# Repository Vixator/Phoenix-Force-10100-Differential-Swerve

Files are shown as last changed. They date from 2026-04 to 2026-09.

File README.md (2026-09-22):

# Differential Swerve Drivetrain

This project implements a two-pod **differential swerve** drivetrain for an FTC robot. Each pod uses two motors whose combined motion controls wheel speed and pod azimuth. Driving and steering share the available motor-speed capacity.

The main TeleOp is **robot-centric** and uses four drive motors and two dedicated pod encoders. Pedro commissioning and autonomous OpModes additionally use a guarded Pinpoint localizer; TeleOp does not require Pinpoint. See [hardware.md](hardware.md) for wiring, specifications, calibration, and tuning notes, [PROJECT_DESIGN.md](PROJECT_DESIGN.md) for architecture and design decisions, and [HUMAN_TASKS.md](HUMAN_TASKS.md) for every physical calibration and commissioning task.

## Pedro integration and verification

The robot pins `com.pedropathing:revhub:3.0.1` and FTC SDK 12.0.0. Pedro commands use forward +X, left +Y, and CCW-positive yaw; positions are inches and headings are radians. `DifferentialSwerveRuntime` owns the shared lifecycle, `DifferentialPod` preserves the calibrated control/motor mapping, and `SafePedroFollower` stops immediately on faults or Stop. Every follower update validates fresh hub feedback, reads Pinpoint once, and checks authorization before each motor write. Autonomous hub recovery cancels the run; TeleOp retains its neutral-stick recovery interlock.

Run `./gradlew.bat :TeamCode:testDebugUnitTest :TeamCode:assembleDebug`. For tests against the neighboring library's actual artifacts and then published Pedro, use `../PedroSwerving/scripts/verify-projects.ps1`. See [INTEGRATION_STATUS.md](INTEGRATION_STATUS.md) for commands, source responsibilities, tested behavior, and limitations.

Pinpoint direction/heading verification and the measured Foresight model remain closed gates. `PedroLineTest`, `PedroCurveTest`, `PedroHeadingTest`, and `PedroAutoTemplate` retain `@Disabled`. Follow [HUMAN_TASKS.md](HUMAN_TASKS.md) in order; successful builds do not authorize changing measured-value flags.

The compiled [PedroAutoTemplate](TeamCode/src/main/java/org/firstinspires/ftc/teamcode/PedroAutoTemplate.java) shows the complete lifecycle:

```java
PedroAutoDrive drive = new PedroAutoDrive(this);
try {
    if (!drive.initialize()) return;
    Follower follower = drive.follower();
    Pose start = new Pose(0, 0, 0);
    Path path = Paths.line(start, new Pose(12, 0, 0)).constant(start.heading());
    follower.holdEnd.set(false);
    waitForStart();
    if (isStopRequested()) return;
    drive.enableForesight(); // Validate measured model while disarmed.
    drive.arm(start);
    follower.follow(path);
    long deadline = System.nanoTime() + 10_000_000_000L;
    while (opModeIsActive() && follower.following() && !drive.hasFault()) {
        if (System.nanoTime() >= deadline) { drive.abort("Path deadline"); break; }
        follower.update();
        idle();
    }
    follower.stop();
    // Also assess terminal pose/velocity: parametric completion alone is not accuracy.
} finally {
    drive.close();
}
```

The path diagnostics additionally detect lack of progress and report `END_WITHIN_TOLERANCE`, `END_OUTSIDE_TOLERANCE`, `INVALID_TERMINAL_FEEDBACK`, `OPERATOR_STOP`, or `FAULT`. Endpoint acceptance checks 0.5 in, 3 degrees, 1 in/s, and 5 degrees/s independently of Foresight's completion flag. Out-of-tolerance/invalid completion latches a fault.

`Pedro Drive Characterization` logs signed timestamped CSV samples under the `PedroCharacterization` Robot Controller log tag at up to 50 Hz, including body velocity, pose, commands, drive scale, and battery voltage. Its telemetry runs at 10 Hz. See the collection and fitting procedure in [HUMAN_TASKS.md](HUMAN_TASKS.md).

## Hardware Configuration

The [drive TeleOp](TeamCode/src/main/java/org/firstinspires/ftc/teamcode/DifferentialSwerveTeleOp.java) expects four goBILDA 5203-2402-0005, 1150 RPM motors on the Control Hub:

| Port | Name | Description |
| :--- | :--- | :--- |
| `0` | `motor0` | Left Pod: LEFT Motor |
| `1` | `motor1` | Left Pod: RIGHT Motor |
| `2` | `motor2` | Right Pod: LEFT Motor |
| `3` | `motor3` | Right Pod: RIGHT Motor |

All four drive motors use software direction `FORWARD`. Individual testing confirmed joystick-up/positive command rotates `motor0` and `motor2` counterclockwise, while `motor1` and `motor3` rotate clockwise, viewed from above; joystick-down reverses each response. Physical testing found that the right pod requires its logical motor pair to be negated and swapped at the hardware boundary. This reverses equal-command wheel drive while leaving opposite-command pod steering unchanged. Drive-motor encoders provide motor velocity/count feedback, but the active drive controller uses the dedicated pod quadrature encoders for pod-position feedback.

Two **Melonbotics Through Bore Encoders** provide absolute analog startup position and quadrature tracking. Their quadrature connections on the Expansion Hub are unchanged:

| Encoder Port | Configuration Name | Measurement |
| :--- | :--- | :--- |
| `0` | `encoderleft` | Left pod azimuth |
| `1` | `encoderright` | Right pod azimuth |

Configure these names on the corresponding Expansion Hub **motor channels** so the SDK can access the encoder inputs. No motors need to be attached; quadrature channels are read-only and never receive output or hardware-reset commands. The diagnostic’s explicit alignment action commands only the selected drive pod motors. Each encoder body contains both outputs and is mechanically **1:1 with pod rotation**. Melonbotics specifies **1024 CPR quadrature output resolution** on the 4-pin JST. The code uses **4096 raw counts per pod revolution**: a power-of-two scale consistent with the 1024 CPR encoder using 4x quadrature decoding and the approximately 4100-count measurement from both pods.

| Control Hub Analog Channel | Configuration Name | Measurement |
| :--- | :--- | :--- |
| `0` | `absencleft` | Left pod absolute azimuth |
| `1` | `absencright` | Right pod absolute azimuth |

Both analog signals use **ONE joiner cable into the physical analog connector labeled 0-1**. They remain independent inputs and require **two hardware names**, not one shared name. Move one pod at a time to verify channel assignment. The encoder output is **0..3.2 V** at 3.3 V supply; raw angle is `volts / 3.2 * 360`, not scaled by the hub's maximum input voltage. See [hardware.md](hardware.md) for manufacturer sources.

## Controls

Select **Differential Swerve TeleOp** on the Driver Station.

- **Left stick:** Robot-relative direction and speed. Up means robot-forward, right means robot-right. Translation uses a radial deadband followed by linear magnitude scaling.
- **Right stick X:** Rotation about the midpoint between the pods. Right commands clockwise/right rotation viewed from above. Rotation uses a deadband and cubic shaping. The measured pod-steering motor polarity is applied separately inside each pod controller.
- **Full-stick rotation:** With translation centered and pods aligned, both pods receive the physical motor signs needed to roll their wheels in opposite chassis directions (about ±2781 ticks/s). Left turn reverses these signs. Steering corrections retain priority, and combined translation/rotation is normalized to fit the motor limits.
- **Release right stick:** Commands zero chassis rotation; it does not actively hold a heading.
- **Triggers:** Not used for driving.

### Startup

1. Complete the physical calibration and verification checklist in [HUMAN_TASKS.md](HUMAN_TASKS.md) first. The measured top-dead-center references are now recorded as `LEFT_FORWARD_DEGREES = 13.725` (0.122 V) and `RIGHT_FORWARD_DEGREES = 29.025` (0.258 V). `CALIBRATION_VERIFIED` is now `true`; hardware configuration, encoder signs/scale, individual motor behavior, and combined pod steering direction have been verified. Previously reported low-speed driving passed; repeat those checks after the shared-runtime refactor, then finish fault testing and loaded tuning.
2. Press **INIT** with the wheels securely raised for commissioning. **The pods move during INIT:** the drive immediately steers both to their independent analog forward references.
3. Alignment is capped at 0.20 command and must remain inside a 2° target window for 100 ms before completion, within a 5-second timeout. Either pod failing stops both. Wait for **READY — pods aligned. Press Start to drive.** Motors receive zero velocity while waiting. An early Start cannot bypass unfinished alignment.
4. Press **Start** to drive. A fresh snapshot verifies the pods are still aligned and seeds quadrature with the measured residual angle. Moving a pod away from forward while waiting requires reinitialization. Runtime then uses quadrature only. At zero requested pod velocity the previous azimuth target is retained. A completely zero chassis request sends true zero to every motor with BRAKE; it does not actively steer.

Analog readings accept 0..3.3 V; the 3.2..3.3 V upper margin is clamped to the wrap endpoint while angle conversion retains the documented 3.2 V scale. Alignment telemetry shows both raw voltages, and analog faults report the measured voltage. The previous exact-3.2 V cutoff could reject a slightly overscale reading; the earlier generic fault did not establish the actual voltage.

An invalid hub read immediately commands zero velocity, then retries the complete snapshot up to three total attempts within 150 ms, with 10 ms between attempts. A recovered read during driving requires both sticks centered before motion resumes and checks analog/quadrature agreement without reseeding. Persistent failure or a loop delay above 250 ms latches a **DRIVE STOPPED** telemetry state until Stop/reinitialization instead of throwing an uncaught feedback exception. Telemetry/logs identify the configured hub, connection, and recovered-read count. Real motor response and communication recovery still require robot testing.

### Investigating an intermittent stopped pod

The drive now publishes numeric Dashboard series for each motor's target velocity, measured velocity, and encoder count, plus each pod's requested speed, drive/steer commands, angle error, quadrature angle/count/rate, absolute voltage/angle, and wrapped `quadrature minus absolute (deg)`. Motor and analog readings reuse the bulk snapshots. Absolute angles are diagnostic during normal driving; they do not correct or reseed quadrature.

If the right pod stops, capture these values **before using counterclockwise rotation to recover it**, including a brief translation-only request with the rotation stick centered:

- Graph `motor2 target (ticks/s)` and `motor3 target (ticks/s)` against their `measured (ticks/s)` series. Nonzero targets with near-zero measured speeds point toward motor response, velocity-loop, encoder, or mechanical trouble; they do not by themselves identify which one. Counts help distinguish actual movement from a bad velocity reading.
- Compare `Right requested speed (normalized)`, `Right drive command`, `Right steer command`, and `Right angle error (deg)`. Drive is deliberately suppressed near a 90-degree steering error, but steering should continue. A zero wheel-speed average alone does not mean both motors are stopped.
- Compare `Right quadrature angle (deg)` against `Right absolute angle (deg)`. A persistent discrepancy while stationary suggests a feedback/calibration problem. Brief differences during motion may reflect the two hubs' sampling times.
- Forward plus clockwise turn can cancel the right pod's requested vector, holding its previous angle. Centering rotation must restore a translation request. Remaining stuck after that is not explained by this normal cancellation.

The reported symptom is an intermittent right-module stop relieved by rotation-stick input; the exact triggering inputs and whether translation alone clears it are unconfirmed. Two code paths can resemble this:

- **Partial-stick cancellation:** roughly 16.875% forward stick and 52.5% clockwise turn stick produce equal forward and rotation contributions at the right pod. Its requested speed becomes zero while the left still drives. Increasing or decreasing rotation removes the cancellation. Near-cancellation produces very low speed, and even a small sideways input can change the requested pod angle sharply.
- **Alignment suppression plus unsuccessful steering:** cosine-squared scaling leaves about 3% of wheel drive at 80° error and zero at 90°. The controller still requests steering, capped at 20% of maximum motor velocity (about 556 ticks/s per motor in pure steering, not a 20% electrical-power limit). If the physical pod cannot execute that correction, wheel drive stays suppressed. Rotation input changes the target angle and can restore drive without the pod first moving. This explains a possible mechanism, not a confirmed hardware fault.

Controller tests cover those two command patterns and mixed-input histories followed by translation using a simple motor/encoder model on both pods. They do not reproduce real friction, binding, hub velocity-loop behavior, or intermittent wiring faults. SDK 12.0 source review confirms that explicit `getBulkData()` refreshes the manual cache and `setMotorVelocity()` sends a velocity command on every call. Neither is a change-only cache requiring joystick movement to refresh it. The stall has not been attributed to a confirmed code defect; record a Dashboard graph or Driver Station video of the event to identify the next targeted fix.

### Encoder Test

Select [Swerve Pod Encoder Test](TeamCode/src/main/java/org/firstinspires/ftc/teamcode/SwervePodEncoderTest.java). Its normal measurement path is read-only, and its explicit Y alignment action commands only the selected pod’s drive motors. It works during INIT or after Start.

1. Run [Pod Analog Encoder Test](TeamCode/src/main/java/org/firstinspires/ftc/teamcode/PodAnalogEncoderTest.java). LB selects the left pod, RB selects the right pod, A steers the selected pod toward its configured forward analog reference, and B aborts. If a reference has not yet been entered, the test targets analog 0 degrees. Confirm `absencleft` is left/channel 0 and `absencright` is right/channel 1.
2. Run [Individual Motor Drive Test](TeamCode/src/main/java/org/firstinspires/ftc/teamcode/MotorEncoderDriveTest.java) with the robot raised. D-pad selects `motor0`–`motor3` for individual checks. Hold LB to drive the left pod or RB to drive the right pod using the real differential mix; left stick is drive, right stick X is steering, and combined output is capped at 420 ticks/s. The current differential topology is known: each motor drives its own 16:54 path, the 54-tooth gear is fixed to a 50-tooth gear, and the two 50-tooth gears engage the common 19-tooth wheel gear.
3. Run [Swerve Pod Encoder Test](TeamCode/src/main/java/org/firstinspires/ftc/teamcode/SwervePodEncoderTest.java). LB/RB select the pod, A zeroes the selected quadrature display in software, X starts/finishes a manual 360-degree measurement, Y steers the selected pod to its analog forward reference, and B aborts alignment.
4. Check the corresponding quadrature channel and verify a complete revolution is approximately 4096 raw counts with the correct clockwise sign.
5. Confirm wheel rolling without pod rotation does not change the pod encoder reading. The analog zero references are recorded as left 0.122 V / 13.725° and right 0.258 V / 29.025°. Both analog voltages decrease during clockwise rotation, so both analog signs are `-1`. Powered testing confirmed that forward wheel drive, low-speed translation, strafing, rotation, combined motion, and stopping work on the robot. Loaded speed, thermal/current validation, fault handling, and final PID tuning remain; hardware PID tuning is planned through the installed FTC Dashboard dependencies.

The combined test shows raw counts, quadrature degrees, analog voltage/raw degrees, target/error, wrap margins, and full-revolution results during INIT and run. Dedicated [Pod Analog Encoder Test](TeamCode/src/main/java/org/firstinspires/ftc/teamcode/PodAnalogEncoderTest.java) and [Individual Motor Drive Test](TeamCode/src/main/java/org/firstinspires/ftc/teamcode/MotorEncoderDriveTest.java) OpModes are also available. Quadrature zeroes and measurements are intentionally **session-only**, with no hardware reset, persistence, or automatic transfer to the drive; record the results in `HUMAN_TASKS.md` and then update the shared constants.

## Implementation Details

### Kinematics
The code calculates each pod's requested travel vector, then combines wheel drive and steering into motor velocity commands:
- `left motor velocity = drive velocity + steer velocity`
- `right motor velocity = drive velocity - steer velocity`

**Steering polarity fix:** Positive differential steering (`left+ / right−`) physically rotates both pods counterclockwise, while calibrated pod angles increase clockwise. The runtime controller now applies `steer = -(Kp * angleError - Kd * measuredRate)`, matching the working startup alignment. Previously the runtime sign was reversed, causing corrections and damping to reinforce unwanted motion. This explains why alignment could work but joystick motion triggered runaway steering. Chassis right-stick input is clockwise-positive; it is not inverted to compensate for individual pod steering.

Runtime steering defaults are `Kp=0.5`, `Kd=0.01`, a `0.20` steering cap, and a `2.0/s` slew limit. Driver Station telemetry shows each pod's measured angle, optimized target, error, motor velocity targets, and signed left/right module wheel speeds in m/s. Positive module speed is robot-forward and negative is robot-reverse. Module speed is calculated from the average measured velocity of the pod's two motors and the configured encoder, gear, and wheel constants; it is wheel-speed feedback, not independently measured ground speed. These are preliminary settings for robot verification.

Motor commands and velocity telemetry use **encoder ticks/second**, not RPM. The supplied motor specification is 1150 RPM no-load, 5.2:1 planetary gearing, 28 pulses per encoder-shaft revolution, and 145.1 pulses per gearbox-output revolution. The calculated motor limit is approximately 2781.08 ticks/second. Steering receives priority when the combined requests exceed motor capacity; wheel drive uses the remaining headroom.

### Mechanical Ratio and Steering Calibration

The programmed differential gear setup uses a 1:1 initial bevel pair for each motor, then a 16-tooth gear driving a 54-tooth gear. Each 54-tooth gear is rigidly attached to a 50-tooth gear, and the two 50-tooth gears engage the common 19-tooth wheel gear. The programmed wheel-drive ratio is `(16/54) * (50/19) = 0.779727`. Equal motor components drive the wheel; the difference between the motor components steers the pod. This is the ratio and topology reflected in the BOM and source code; the old 24/108 gear description is obsolete.

The 63.25 mm wheel and 1150 RPM motor rating produce a theoretical no-load wheel speed of approximately 2.970 m/s. This is not a loaded operating limit.

### Steering Calibration
The shared [SwervePodEncoder](TeamCode/src/main/java/org/firstinspires/ftc/teamcode/SwervePodEncoder.java) seeds azimuth at Start with `wrap((rawAnalogDegrees - forwardDegrees) * analogSign)`, then uses only the dedicated Expansion Hub quadrature encoders:
`deltaPodAngle = deltaPodEncoderCounts * quadratureSign * (2 * PI / COUNTS_PER_REVOLUTION)`

There is **no runtime analog correction**. Raw controller reads preserve measured polarity independently of motor-channel direction settings. Steering damping uses pod angular rate calculated from successive counts and elapsed time. Both analog signs are `-1`: each encoder's raw voltage decreases during clockwise pod rotation viewed from above. Both quadrature signs are confirmed as `+1` because clockwise motion increases raw counts.

Independent `LEFT_FORWARD_DEGREES` and `RIGHT_FORWARD_DEGREES` absorb the right module's 180-degree mounting rotation. It is rotated, **not mirrored**: do not negate right feedback or add another 180 degrees merely because of its mounting. Both pods remain centered at their existing left/right locations with unchanged kinematics. Encoder calibration does not validate motor directions.

Mechanically indexing each encoder near **1.6 V = 180 raw degrees** at directed forward gives room for +/-100 degrees (about 80 degrees left to the wrap) or +/-80 degrees (about 100 degrees left). A software forward offset does not move the hardware DAC wrap. The analog wrap is neither a dead zone nor a hard steering limit.

### Optimizations
- **Shortest-path steering:** Wheel direction reverses when the equivalent azimuth is closer. A 3° hysteresis band around 90° prevents repeated reversals from small input/encoder noise; the retained choice can require up to 93° of steering. Wheel drive is zero for errors at or above 90°.
- **Alignment scaling:** Wheel drive is reduced by cosine-squared steering error while the pod is misaligned.
- **Steering slew limiting:** Time-based limiting reduces abrupt changes to the steering command.
- **Bulk reads:** One validated snapshot per configured hub per drive loop; encoder getters reuse that snapshot.
- **Telemetry:** Updates at 10 Hz and reuses stored pod counts. Requested-vector angles may differ from optimized pod angles when wheel direction is reversed.
- **Velocity PIDF:** Applied during INIT and reapplied to all four drive motors whenever a Dashboard value changes.

### Tuning and Validation

FTC Dashboard 0.6.0 is installed. The embedded Dashboard server starts with the Robot Controller app; no separate server process is needed for normal use.

1. Build and install the Robot Controller app after dependency changes: `./gradlew.bat :TeamCode:assembleDebug`. Deploy it from Android Studio or with your normal ADB workflow.
2. Connect the computer to the Control Hub Wi-Fi network. Find its password in the Driver Station's **Program and Manage** screen if needed.
3. Open `http://192.168.43.1:8080/dash` for a Control Hub. A phone Robot Controller using Wi-Fi Direct normally uses `http://192.168.49.1:8080/dash` instead.
4. Initialize **Differential Swerve TeleOp**. Open **Config**, expand **SwerveTuning**, edit a value, and press Enter. Runtime steering values take effect on the next control loop. Changed motor PIDF values are detected and written to all four motors while the OpMode runs.
5. Use the Dashboard telemetry graph to select angle/error, motor target velocity, or `Module wheel speed (m/s)` series. Continue to operate the robot from the Driver Station; browser gamepad control is not recommended for drivetrain tuning.

The `SwerveTuning` panel contains all active closed-loop drivetrain settings:

| Dashboard field | Default | Function |
| :--- | ---: | :--- |
| `MOTOR_VELOCITY_P` | `15.0` | REV motor velocity proportional gain |
| `MOTOR_VELOCITY_I` | `0.5` | REV motor velocity integral gain |
| `MOTOR_VELOCITY_D` | `0.5` | REV motor velocity derivative gain |
| `MOTOR_VELOCITY_F` | `11.782...` | REV motor velocity feedforward gain |
| `STEERING_P` | `0.5` | Runtime pod-angle proportional gain, using radians |
| `STEERING_D` | `0.01` | Runtime pod angular-rate damping gain, using rad/s |
| `STEERING_MAX_COMMAND` | `0.20` | Maximum differential steering command |
| `STEERING_SLEW_RATE` | `2.0` | Maximum steering-command change per second |
| `ALIGNMENT_P` | `0.005` | INIT absolute-alignment proportional gain, using degrees |
| `ALIGNMENT_MIN_COMMAND` | `0.03` | Minimum INIT alignment command outside the 2° settling window, to overcome static friction |
| `ALIGNMENT_MAX_COMMAND` | `0.20` | Maximum INIT alignment command |

Dashboard edits change live in-memory values only. Record successful gains and update the defaults in [`SwerveTuning.java`](TeamCode/src/main/java/org/firstinspires/ftc/teamcode/SwerveTuning.java) before rebuilding; do not assume browser edits will survive an app restart or redeployment. Values are validated as finite and nonnegative, command limits must be in `0..1`, the minimum cannot exceed the maximum, and an invalid value stops the OpMode. Tune with the robot raised initially, keep clear during INIT alignment, and change one control layer at a time: motor velocity PIDF first, runtime steering PD second, then INIT alignment P.

The no-load wheel-speed estimate is not a measured loaded limit. Stick deadbands and kinematic limits remain source constants because they are not PIDF controller settings.

The debug APK build and unit tests passed using `./gradlew.bat :TeamCode:testDebugUnitTest :TeamCode:assembleDebug`. Tests cover encoder math, startup/runtime correction agreement, damping direction, strafing, chassis rotation, reverse travel, angle wrap, motor limits, target retention, and closed-loop convergence using a simple motor model. Real-robot testing has additionally confirmed forward wheel drive, low-speed translation, strafing, rotation, combined motion, and stopping. The model verifies feedback direction, not physical tuning. Complete the real-world commissioning checks in [HUMAN_TASKS.md](HUMAN_TASKS.md); tests do not establish physical stability, loaded speed, or hardware loop timing. **Zero volts can be a valid absolute position or a disconnected sensor**; range checks are not reliable disconnect protection. Frozen/disconnected quadrature feedback can also return valid hub data, and runtime analog correction or reliable sensor-disconnect detection is not implemented.

Build from the repository root on Windows with `./gradlew.bat :TeamCode:assembleDebug`.

---

## FOR HACKCLUB STARDANCE
My project is a differential swerve drivetrain for an FTC robot. A differential swerve drive is a holonomic drive, which allows the robot to move in any direction at any time. A differential drive is different from a co-axial swerve drive (used in FRC) as it uses both motors for thrust and direction instead of using one per. This allows for double the power while moving forward and turning, resulting in a faster drivetrain. I made this project mainly for fun and to test my skills in designing and manufacturing. It could benefit my robotics team in the next season, but that varies depending on the actual game presented. 

FINAL ASSEMBLY V1: Too large and not correct speed


V2 In progress, need parts to finish assembly.
\



------------------------------------------------------------------------------------------------------------------------------------------------------------------
## NOTICE

This repository contains the public FTC SDK for the BIOBUZZ (2026-2027) competition season.

## Welcome!
This GitHub repository contains the source code that is used to build an Android app to control a *FIRST* Tech Challenge competition robot.  To use this SDK, download/clone the entire project to your local computer.

## Requirements
To use this Android Studio project, you will need Android Studio Narwhal 3 Feature Drop or later.

To program your robot in Blocks or OnBot Java, you do not need Android Studio.

## Getting Started
If you are new to robotics or new to the *FIRST* Tech Challenge, then you should consider reviewing the [FTC Blocks Tutorial](https://ftc-docs.firstinspires.org/programming_resources/blocks/Blocks-Tutorial.html) to get familiar with how to use the control system:

&nbsp;&nbsp;&nbsp;&nbsp;&nbsp;&nbsp;[FTC Blocks Online Tutorial](https://ftc-docs.firstinspires.org/programming_resources/blocks/Blocks-Tutorial.html)

Even if you are an advanced Java programmer, it is helpful to start with the [FTC Blocks tutorial](https://ftc-docs.firstinspires.org/programming_resources/blocks/Blocks-Tutorial.html), and then migrate to the [OnBot Java Tool](https://ftc-docs.firstinspires.org/programming_resources/onbot_java/OnBot-Java-Tutorial.html) or to [Android Studio](https://ftc-docs.firstinspires.org/programming_resources/android_studio_java/Android-Studio-Tutorial.html) afterwards.

## Downloading the Project
If you are an Android Studio programmer, there are several ways to download this repo.  Note that if you use the Blocks or OnBot Java Tool to program your robot, then you do not need to download this repository.

* If you are a git user, you can clone the most current version of the repository:

<p>&nbsp;&nbsp;&nbsp;&nbsp;&nbsp;&nbsp;&nbsp;&nbsp;&nbsp;&nbsp;&nbsp;&nbsp;git clone https://github.com/FIRST-Tech-Challenge/FtcRobotController.git</p>

* Or, if you prefer, you can use the "Download Zip" button available through the main repository page.  Downloading the project as a .ZIP file will keep the size of the download manageable.

* You can also download the project folder (as a .zip or .tar.gz archive file) from the Downloads subsection of the [Releases](https://github.com/FIRST-Tech-Challenge/FtcRobotController/releases) page for this repository.

* The Releases page also contains prebuilt APKs.

Once you have downloaded and uncompressed (if needed) your folder, you can use Android Studio to import the folder  ("Import project (Eclipse ADT, Gradle, etc.)").

## Getting Help
### User Documentation and Tutorials
*FIRST* maintains online documentation with information and tutorials on how to use the *FIRST* Tech Challenge software and robot control system.  You can access this documentation using the following link:

&nbsp;&nbsp;&nbsp;&nbsp;&nbsp;&nbsp;[FIRST Tech Challenge Documentation](https://ftc-docs.firstinspires.org/index.html)

Note that the online documentation is an "evergreen" document that is constantly being updated and edited.  It contains the most current information about the *FIRST* Tech Challenge software and control system.

### Javadoc Reference Material
The Javadoc reference documentation for the FTC SDK is now available online.  Click on the following link to view the FTC SDK Javadoc documentation as a live website:

&nbsp;&nbsp;&nbsp;&nbsp;&nbsp;&nbsp;[FTC Javadoc Documentation](https://javadoc.io/doc/org.firstinspires.ftc)

### Online User Forum
For technical questions regarding the Control System or the FTC SDK, please visit the FIRST Tech Challenge Community site:

&nbsp;&nbsp;&nbsp;&nbsp;&nbsp;&nbsp;[FIRST Tech Challenge Community](https://ftc-community.firstinspires.org/)

### Sample OpModes
This project contains a large selection of Sample OpModes (robot code examples) which can be cut and pasted into your /teamcode folder to be used as-is, or modified to suit your team's needs.

Samples Folder: &nbsp;&nbsp; [/FtcRobotController/src/main/java/org/firstinspires/ftc/robotcontroller/external/samples](FtcRobotController/src/main/java/org/firstinspires/ftc/robotcontroller/external/samples)

The readme.md file located in the [/TeamCode/src/main/java/org/firstinspires/ftc/teamcode](TeamCode/src/main/java/org/firstinspires/ftc/teamcode) folder contains an explanation of the sample naming convention, and instructions on how to copy them to your own project space.

# Release Information

## Version 12.0 (20260907-090034)

### Breaking Changes
* The new AprilTag Cluster capability breaks legacy AprilTag OpModes resulting in compile errors for software that uses AprilTagDetection objects in both Android Studio and OnBot Java.
  * Legacy AprilTag OpModes must be updated to check whether the returned AprilTag is a cluster or singleton,
     and cast the returned detection into the correct type to access its elements.  See below:    
     
	 **Old method for AprilTag processing**
    ```
     for (AprilTagDetection detection : currentDetections) {
       // Do single Tag processing here  
     }
    ```

     **New method for AprilTag Singleton/Cluster processing**

    ```
     for (AprilTagDetection detection : currentDetections) {
       if (detection instanceof AprilTagSingleDetection) {
         AprilTagSingleDetection singleDet = (AprilTagSingleDetection) detection;
         // Do single Tag processing here  
       } else {
         AprilTagClusterDetection clusterDet = (AprilTagClusterDetection) detection;
         // Do cluster Tag processing here  
       }
     }
     ```
    For more information about how to update your OpModes to fix the breaking change see: https://ftc-docs.firstinspires.org/apriltag-clusters
    
  * About AprilTag clusters:  
    * Clusters are co-planar groups of two or more AprilTags wherein the position of each member tag is defined relative to a common origin
    * This origin may be placed outside the bounds of the tags themselves to provide a more suitable "aiming" target
    * Clusters are resilient to partial occlusion. Full 6DOF pose can be estimated from a cluster even if only a single member tag is visible. Of course, the more tags that are visible, the better and more stable the pose estimate will be
    * All AprilTag samples have been updated to differentiate between standalone tags and clusters
  
### Enhancements
* Adds a tree view for robot configurations [issue 1821](https://github.com/FIRST-Tech-Challenge/FtcRobotController/issues/1821)
* Gamepad indicators on the Driver Station are now colored orange if the respective gamepads are connected to the Android generic gamepad driver instead of the Driver Station's usermode USB driver 
* Updated AprilTag Library for BIOBUZZ. Notably, getCurrentGameTagLibrary() now returns BIOBUZZ tags.
  * In BIOBUZZ, the Origin of each cluster is located in the center of the Cell opening for easy aiming.
  * The Origin X,Y & Z Axes are now displayed by default on the preview image.
  * <B>Unfortunately, since BIOBUZZ AprilTags move, they are not suitable for absolute Field Localization.</B>
* Supports OctoQuad MK2 firmware v3.1.0, which adds diagnostics parameters for the IMU and MCU uptime

### Bug Fixes
* Fixes issue [2078](https://github.com/FIRST-Tech-Challenge/FtcRobotController/issues/2078) where battery
voltage was not updated on driver station if OpMode did not send any telemetry.

## Version 11.2.1 (20260724-093406)

### Bug Fixes
* Fixes issue [2099](https://github.com/FIRST-Tech-Challenge/FtcRobotController/issues/2099). Gradle and the AGP are now updated to 9.1 and 8.13.2 respectively.
 
## Version 11.2 (20260707-102819)

### Breaking Changes
* Gradle is upgraded to v9.1 and the Android Gradle Plugin is updated to v8.13.2.  AGP v8.13.2 requires Android Studio Narwhal 3 Feature Drop or later.  Earlier versions of Android Studio will fail to sync the project.  Older versions of Android Studio may prompt the user to downgrade AGP.  Do not do this.  Gradle v9.1 removed support for features that older versions of the AGP use. Updating Gradle fixes a Windows 11 problem some teams may encounter if they have agressive security software installed on their machine.  For more context see [this Gradle issue](https://github.com/gradle/gradle/issues/31438)

### Enhancements
* New type of OpMode is now available. (`@Utility`)
   * Utility opmodes that are not disabled will show up in the Utility menu (requires 11.2 or later DS and RC) 
* TestHardware Utility now available
  * It allows you to test all servos, CR servos, motors, Color sensors, distance sensors, touch sensors, IMUs, webcams, and analog sensors in the config
* TestGamepad Utility now available
  * It allows you to see the results of your two gamepads to make sure it is what you expect and find problems with your gamepads. 
* Adds methods to PwmControl interface to allow you to setPulseWidth and getPulseWidth 
   * Both of these are in microseconds (uSeconds)
   * This is an ADVANCED feature.   There is not a supporting sample.
   * NOTE: You may see a slight difference since the hardware is not accurate to the microsecond
* Adds ability to set UVC camera "quirks" from user code to control compatibility flags used inside the low level UVC driver. Addresses issue [1428](https://github.com/FIRST-Tech-Challenge/FtcRobotController/issues/1428)
* Changes Apriltag Axis Display order on camera preview screen, to reflect updated Z axis direction.
* The Driver Station app init button has a light teal background with the word init if
   * the driver station and robot controller are connected and have the same team number
   * there is at least one gamepad attached
   * the timer is enabled (for an Autonomous OpMode)

### Bug Fixes
* Fixes issue [1949](https://github.com/FIRST-Tech-Challenge/FtcRobotController/issues/1949) overwriting the group with the default group when registering a OpMode with OpModeManager.register(OpModeMeta name, Class<? extends OpMode> clazz)
* Fixes issue mentioned in [1890](https://github.com/FIRST-Tech-Challenge/FtcRobotController/issues/1890) where if 
  for a servo you change the direction or scaleRange and send the same setPosition that was sent 
  before, then it wouldn't update the servo.
* Fixes an issue where Self-Inspect doesn't flag a driver station using -RC in it's name. The message is now:
  * The team numbers in the robot controller and driver station names do not match, or a device name is invalid. Refer to the FTC Competition Manual for device naming rules.

## Version 11.1 (20251231-104637)

### Enhancements

* Gamepad triggers can now be accessed as booleans and have edge detection supported.
* GoBildaPinpointDriver now supports Pinpoint v2 functionality
* Adds webcam calibrations for goBILDA's USB camera.

### Bug Fixes
* Fixes issue [1654](https://github.com/FIRST-Tech-Challenge/FtcRobotController/issues/1654) in GoBildaPinpointDriver that caused error if resolution was set in other than MM
* Fixes issue [1628](https://github.com/FIRST-Tech-Challenge/FtcRobotController/issues/1628) Blocks editor displays incorrect Java code for gamepad edge detection blocks.
* Fixes possible race condition issue [1884](https://github.com/FIRST-Tech-Challenge/FtcRobotController/issues/1884) on Driver Station startup when Driver Station name doesn't match the Robot Controller name.
* Fixes issue [1863](https://github.com/FIRST-Tech-Challenge/FtcRobotController/issues/1863) - Incorrect package paths in samples.
* Fixes an issue where an OnBotJava filename that begins with a lowercase character would fail to properly rename the file if the user tried to rename it so that it begins with an uppercase character.

## Version 11.0 (20250827-105138)

### Enhancements

* OnBotJava now has the concept of a project.  
  A project is a collection of related files.  A project may be chosen by selecting 'Example Project'
  from the 'File type:' dropdown.  Doing so will populate the dropdown to the immediate right with 
  a list of projects to choose from.
  When selecting a project all of the related files appear in the left pane of the workspace 
  underneath a directory with the chosen project name.
  This is useful for example for ConceptExternalHardwareClass which has a dependency upon
  RobotHardware.  This feature simplifies the usage of this Concept example by automatically
  pulling in dependent classes.
* Adds support for AndyMark ToF, IMU, and Color sensors.
* The Driver Station app indicates if WiFi is disabled on the device.
* Adds several features to the Color Processing software:
  * DECODE colors `ARTIFACT_GREEN` and `ARTIFACT_PURPLE`
  * Choice of the order of pre-processing steps Erode and Dilate
  * Best-fit preview shape called `circleFit`, an alternate to the existing `boxFit`
  * Sample OpMode `ConceptVisionColorLocator_Circle`, an alternate to the renamed `ConceptVisionColorLocator_Rectangle`
* The Driver Station app play button has a green background with a white play symbol if
  * the driver station and robot controller are connected and have the same team number
  * there is at least one gamepad attached
  * the timer is enabled (for an Autonomous OpMode)
* Updated AprilTag Library for DECODE. Notably, getCurrentGameTagLibrary() now returns DECODE tags.
  * Since the AprilTags on the Obelisk should not be used for localization, the ConceptAprilTagLocalization samples only use those tags without the name 'Obelisk' in them.
* OctoQuad I2C driver updated to support firmware v3.x 
  * Adds support for odometry localizer on MK2 hardware revision
  * Adds ability to track position for an absolute encoder across multiple rotations
  * Note that some driver APIs have changed; minor updates to user software may be required
  * Requires firmware v3.x. For instructions on updating firmware, see
    https://github.com/DigitalChickenLabs/OctoQuad/blob/master/documentation/OctoQuadDatasheet_Rev_3.0C.pdf

## Version 10.3 (20250625-090416)

### Breaking Changes
* The behavior of setGlobalErrorMsg() is changed.  Note that this is an SDK internal method that is not 
  meant to be used by team software or third party libraries.  Teams or libraries using this method should
  find another means to communicate failure.  The design intent of setGlobalErrorMsg() is to report an 
  error and force the user to restart the robot, which in certain circumstances when used inappropriately
  could cause a robot to continue running while Driver Station controls are disabled.  To prevent this,
  processing of a call to setGlobalErrorMsg() is deferred until the robot is in a known safe state.  This may
  mean that a call to setGlobalErrorMsg() that does not also result in stopping a running OpMode will appear
  as though nothing happened until the robot is stopped, at which point, if clearGlobalErrorMsg() has not 
  been called the message will appear on the Driver Station and a restart will be required.
  Addresses issue [1381](https://github.com/FIRST-Tech-Challenge/FtcRobotController/issues/1381)
* Fixes getLatestResult in Limelight3A so if the Limelight hasn't provided data yet, it still returns an LLResult but valid will be false
  * If you previously used to check and see if this was `null` to see if the Limelight had been contacted, you now need to use `isValid()` on the result.  That is because now it always returns an LLResult even before it talks to the Limelight, but if it doesn't have valid data, the `isValid()` will be `false`.
* Changed all omni samples to use front_left_drive, front_right_drive, back_left_drive, back_right_drive
  * This is only breaking for you if you copy one of the changed samples to your own project and expect to use the same robot configuration as before.

### Known Issues
* The redesigned OnBotJava new file workflow allows the user to use a lowercase letter as the first character of a filename.
  This is a regression from 10.2 which required the first character to be uppercase.  Software will build, but if the user tries
  to rename the file, the rename will fail.

### Enhancements
* Adds a configuration item for a Full Range Servo.  Selecting this item expands the pulse width range from 500us to 2500us.  For comparison, the legacy Servo type defines the pulse width range as 600us to 2400us.
* Improved the OBJ new file creation flow workflow. The new flow allows you to easily use samples, craft new custom OpModes and make new Java classes.
* Added support for gamepad edge detection.
  * A new sample program `ConceptGamepadEdgeDetection` demonstrates its use.
* Adds a blackboard member to the Opmode that maintains state between opmodes (but not between robot resets).  See the ConceptBlackboard sample for how to use it.
* Updated PredominantColorProcessor to also return the predominant color in RGB, HSV and YCrCb color spaces.  Updated ConceptVisionColorSensor sample OpMode to display the getAnalysis() result in all three color spaces.
* Adds support for the GoBilda Pinpoint 
  * Also adds `SensorGoBildaPinpoint` sample to show how to use it
* Added `getArcLength()` and `getCircularity()` to ColorBlobLocatorProcessor.Blob.  Added BY_ARC_LENGTH and BY_CIRCULARITY as additional BlobCriteria.
* Added `filterByCriteria()` and `sortByCriteria()` to ColorBlobLocatorProcessor.Util.
  * The filter and sort methods for specific criteria have been deprecated.
  * The updated sample program `ConceptVisionColorLocator` provides more details on the new syntax.
* Add Help menu item and Help page that is available when connected to the robot controller via Program and Manage. The Help page has links to team resources such as [FTC Documentation](https://ftc-docs.firstinspires.org/), [FTC Discussion Forums](https://ftc-community.firstinspires.org), [Java FTC SDK API Documentation](https://javadoc.io/doc/org.firstinspires.ftc), and [FTC Game Information](https://ftc.game/).
* Self inspection changes:
  * List both the Driver Station Name and Robot Controller Name when inspecting the Driver Station.
  * Report if the team number portion of the device names do not match.
  * -rc is no longer valid as part of a Robot Controller name, must be -RC.
  * Use Robot Controller Name or Driver Station Name labels on the inspection screens instead of WIFI Access Point or WIFI Direct Name.

### Bug Fixes
* Fixes issue [1478](https://github.com/FIRST-Tech-Challenge/FtcRobotController/issues/1478) in AnnotatedHooksClassFilter that ignored exceptions if they occur in one of the SDK app hooks.
* Fix initialize in distance sensor (Rev 2m) to prevent bad data in first call to getDistance.
* Fixes issue [1470](https://github.com/FIRST-Tech-Challenge/FtcRobotController/issues/1470) Scaling a servo range is now irrespective of reverse() being called.  For example, if you set the scale range to [0.0, 0.5] and the servo is reversed, it will be from 0.5 to 0.0, NOT 1.0 to 0.5.
* Fixes issue [1232](https://github.com/FIRST-Tech-Challenge/FtcRobotController/issues/1232), a rare race condition where using the log rapidly along with other telemetry could cause a crash.

## Version 10.2 (20250121-174034)

### Enhancements
* Add ability to upload the pipeline for Limelight3A which allows teams to version control their limelight pipelines.

### Bug Fixes

* Fix an internal bug where if the RUN_TO_POSITION run mode was specified before a target position, recovery would require a power cycle. A side effect of this fix is that a stack trace identifying the location of the error is always produced in the log. Fixes issue [1345](https://github.com/FIRST-Tech-Challenge/FtcRobotController/issues/1345).
* Throws a helpful exception if region of interest is set to null when building a PredominantColorProcessor. Also sets the default RoI to the full frame. Addresses issue [1076](FIRST-Tech-Challenge/FtcRobotController#1076)
* Throws a helpful exception if user tries to construct an ImageRegion with malformed boundaries.  Addresses issue [1078](FIRST-Tech-Challenge/FtcRobotController#1078)

## Version 10.1.1 (20241102-092223)

### Breaking Changes

* Support for Android Studio Ladybug.  Requires Android Studio Ladybug.  

### Known Issues

* Android Studio Ladybug's bundled JDK is version 21.  JDK 21 has deprecated support for Java 1.8, and Ladybug will warn on this deprecation.
  OnBotJava only supports Java 1.8, therefore, in order to ensure that software developed using Android Studio will 
  run within the OnBotJava environment, the targetCompatibility and sourceCompatibility versions for the SDK have been left at VERSION_1_8.
  FIRST has decided that until it can devote the resources to migrating OnBotJava to a newer version of Java, the deprecation is the 
  lesser of two non-optimal situations.

### Enhancements

* Added `toString()` method to Pose2D
* Added `toString()` method to SparkFunOTOS.Pose2D

## Version 10.1 (20240919-122750)

### Enhancements
* Adds new OpenCV-based `VisionProcessor`s (which may be attached to a VisionPortal in either Java or Blocks) to help teams implement color processing via computer vision in the INTO THE DEEP game
  * `ColorBlobLocatorProcessor` implements OpenCV color "blob" detection. A new sample program `ConceptVisionColorLocator` demonstrates its use.
    * A choice is offered between pre-defined color ranges, or creating a custom one in RGB, HSV, or YCrCb color space
    * The ability is provided to restrict detection to a specified Region of Interest on the screen
    * Functions for applying erosion / dilation morphing to the threshold mask are provided
    * Functions for sorting and filtering the returned data are provided
  * `PredominantColorProcessor` allows using a region of the camera as a "long range color sensor" to determine the predominant color of that region. A new sample program `ConceptVisionColorSensor` demonstrates its use.
    * The determined predominant color is selected from a discrete set of color "swatches", similar to the MINDSTORMS NXT color sensor
  * Documentation on this Color Processing feature can be found here: https://ftc-docs.firstinspires.org/color-processing
* Added Blocks sample programs for color sensors: RobotAutoDriveToLine and SensorColor.
* Updated Self-Inspect to identify mismatched RC/DS software versions as a "caution" rather than a "failure."

### Bug Fixes
* Fixes [AngularVelocity conversion regression](https://github.com/FIRST-Tech-Challenge/FtcRobotController/issues/1070)

## Version 10.0  (20240828-111152)

### Breaking Changes
* Java classes and Blocks for TensorFlow Object Detection have been removed.
* `AngularVelocity.unit` which was of type `AngleUnit` has been renamed `AngularVelocity.angleUnit` of type `UnnormalizedAngleUnit`

### Enhancements
* Sample for REV Digital Indicator has been added - ConceptRevLED
* Adds support for the [Sparkfun QWIIC LED Stick](https://www.sparkfun.com/products/18354)
  * To connect it directly, you need this [cable](https://www.sparkfun.com/products/25596)
* Adds ConceptLEDStick OpMode
* Adds Blocks for colors black, blue, cyan, dkgray, gray, green, ltgray, magenta, red, white, and yellow.
* Adds an "evaluate but ignore result" Block that executes the connected block and ignores the result. Allows you to call a function and ignore the return value.
* Adds I2C driver for Maxbotix Maxsonar I2CXL sonar rangefinder
* Adds Blocks for setPwmEnable, setPwmDisable, and isPwmEnabled for servos and CR servos.
* In the Blocks editor: a \n in the ExportToBlocks annotation's comment field is displayed as a line break.
* Telemetry has new method setNumDecimalPlaces
* Telemetry now formats doubles and floats (not inside objects, just by themselves)
* Adds support for the Limelight 3A.
* Adds initial support for the REV Servo Hub
  * Both the Robot Controller and Driver Station need to be updated to version 10.0 in order for Servo Hubs to be
    configurable as Servo Hubs. If the app on either device is outdated, the Servo Hub will show up as an Expansion Hub,
    and some functionality will not work as expected. You should wait to create a configuration that includes a Servo Hub
    until both the Driver Station and Robot Controller apps have been updated to version 10.0.
  * Updating the Servo Hub's firmware and changing its address can only be done using the REV Hardware Client at this time
* Adds support for the REV 9-Axis IMU (REV-31-3332)
  * The REV 9-Axis IMU is only supported by the [Universal IMU interface](https://ftc-docs.firstinspires.org/en/latest/programming_resources/imu/imu.html)
  * Adds `Rev9AxisImuOrientationOnRobot` Java class.
  * If you mentally substitute this IMU's I2C port for the Control Hub's USB ports, `RevHubOrientationOnRobot` is also compatible with this sensor
  * Adds Blocks for Rev9AxisImuOrientationOnRobot, including RevHubImuOrientationOnRobot.xyzOrientation and  RevHubImuOrientationOnRobot.zyxOrientation.
  * Adds Blocks samples SensorRev9AxisIMUOrthogonal and SensorRev9AxisIMUNonOrthogonal.
* Improves Blocks support for RevHubImuOrientationOnRobot.
  * Adds Blocks for RevHubImuOrientationOnRobot.xyzOrientation and  RevHubImuOrientationOnRobot.zyxOrientation.
  * Adds Blocks samples SensorHubIMUOrthogonal (replaces SensorIMU) and SensorHubIMUNonOrthogonal.
* Updates EasyOpenCV, AprilTag, OpenCV, and `libjpeg-turbo` versions
* Adds Blocks for max and min that take two numbers.
* Adds Blocks OpModes ConceptRevSPARKMini, RobotAutoDriveByEncoder, RobotAutoDriveByGyro, RobotAutoDriveByTime, RobotAutoDriveToAprilTagOmni, and RobotAutoDriveToAprilTagTank.
* Two OpModes with the same name now automatically get renamed with the name followed by a "-" and the class name allowing them to both be on the device.
* Shows the name of the active configuration on the Manage page of the Robot Controller Console
* Updated AprilTag Library for INTO THE DEEP. Notably, `getCurrentGameTagLibrary()` now returns INTO THE DEEP tags.
* Adds Blocks for Telemetry.setMsTransmissionInterval and Telemetry.getMsTransmissionInterval.
* Adds Blocks sample SensorOctoQuad.

### Bug Fixes
* Fixes a bug where the RevBlinkinLedDriver Blocks were under Actuators in the Blocks editor toolbox. They are now Other Devices.
* Fixes a bug where `Exception`s thrown in user code after a stop was requested by the Driver Station would be silently eaten
* Fixed a bug where if you asked for `AngularVelocity` in a unit different than the device reported it in, it would normalize it between -PI and PI for radians, and -180 and 180 for degrees.

## Version 9.2 (20240701-085519)

### Important Notes
* Java classes and Blocks for TensorFlow Object Detection have been deprecated and will be removed in Version 10.0.
* The samples that use TensorFlow Object Detection have been removed.

### Enhancements
* Adds explanatory text to failed items on the inspection activities.  To view the explanatory text tap the red warning icon for a failed item.
* In the Blocks editor: added a new kind of variable set block that sets the variable and also returns the new value.
* Changes the way that camera controls behave for a SwitchableCamera. Now, each method (such as getExposure, getMinExposure, getMaxExposure, setExposure for ExposureControl) acts on the currently active camera.
* Adds support for the REV USB PS4 Compatible Gamepad (REV-31-2983)
* Adds ConceptAprilTagMultiPortal OpMode
* Adds support for OctoQuad Quadrature Encoder & Pulse Width Interface Module
* Adds the ExportAprilTagLibraryToBlocks annotation that indicates that a static method that returns an AprilTagLibrary is exported to the Blocks programming environment. The corresponding block will appear in the Blocks toolbox along with the built-in tag libraries.
* Adds Blocks OpMode ConceptAprilTagOptimizeExposure.
* Adds support for the SparkFun Optical Tracking Odometry sensor.

### Bug Fixes
* Fixes https://github.com/FIRST-Tech-Challenge/FtcRobotController/issues/942 where visionPortal.close() can cause an IndexOutOfBoundsError.
* Fixes a bug in the blocks editor where collapsed function blocks show a warning "Collapsed blocks contain warnings." when the Blocks OpMode is reopened.
* Fixes a bug where the blocks editor wouldn't warn you that you have unsaved changes when you try to leave. This bug was introduced due to a behavior change in Chrome 119.
* [Issue #764](https://github.com/FIRST-Tech-Challenge/FtcRobotController/issues/764) - Get gain control returns a null pointer for a switchable camera
* Fixes a bug where the correct deadzone for certain gamepads was not applied when Advanced Gamepad Features was enabled

## Version 9.1 (20240215-115542)

### Enhancements
* Fixes a problem with Blocks: if the user closes a Block's warning balloon, it will still be closed next time the project is opened in the Blocks editor.
* In the Blocks editor, an alert concerning missing hardware devices is not shown if all the Blocks that use the missing hardware devices are disabled.
* Adds Blocks to support comparing property values CRServo.Direction, DCMotor.Direction, DCMotor.Mode, DCMotor.ZeroPowerBehavior, DigitalChannel.Mode, GyroSensor.HeadingMode, IrSeekerSensor.Mode, and Servo.Direction, to the corresponding enum Block.
* Improves OnBotJava auto-import to correctly import classes when used in certain situations.
* Improves OnBotJava autocomplete to provide better completion options in most cases.
  * This fixes an issue where autocomplete would fail if a method with two or more formal parameters was defined.
* In OnBotJava, code folding support was added to expand and collapse code sections
* In OnBotJava, the copyright header is now automatically collapsed loading new files
* For all Blocks OpMode samples, intro comments have been moved to the RunOpMode comment balloon.
* The Clean up Blocks command in the Blocks editor now positions function Blocks so their comment balloons don't overlap other function Blocks.
* Added Blocks OpMode sample SensorTouch.
* Added Java OpMode sample SensorDigitalTouch.
* Several improvements to VisionPortal
  * Adds option to control whether the stream is automatically started following a `.build()` call on a VisionPortal Builder
  * Adds option to control whether the vision processing statistics overlay is rendered or not
  * VisionPortals now implement the `CameraStreamSource` interface, allowing multiportal users to select which portal is routed to the DS in INIT by calling CameraStreamServer.getInstance().setSource(visionPortal). Can be selected via gamepad, between Camera Stream sessions.
  * Add option to `AprilTagProcessor` to suppress calibration warnings
  * Improves camera calibration warnings
    * If a calibration is scaled, the resolution it was scaled from will be listed
    * If calibrations exist with the wrong aspect ratio, the calibrated resolutions will be listed
  * Fixes race condition which caused app crash when calling `stopStreaming()` immediately followed by `close()` on a VisionPortal
  * Fixes IllegalStateException when calling `stopStreaming()` immediately after building a VisionPortal
  * Added FTC Blocks counterparts to new Java methods:
    * VisionPortal.Builder.setAutoStartStreamOnBuild
    * VisionPortal.Builder.setShowStatsOverlay
    * AprilTagProcessor.Builder.setSuppressCalibrationWarnings
    * CameraStreamServer.setSource

### Bug Fixes
* Fixes a problem where OnBotJava does not apply font size settings to the editor.
* Updates EasyOpenCV dependency to v1.7.1
  * Fixes inability to use EasyOpenCV CameraFactory in OnBotJava
  * Fixes entire RC app crash when user pipeline throws an exception
  * Fixes entire RC app crash when user user canvas annotator throws an exception
  * Use the modern stacktrace display when handling user exceptions instead of the legacy ESTOP telemetry message

## Version 9.0.1 (20230929-083754)

### Enhancements
* Updates AprilTag samples to include Decimation and additional Comments.  Also corrects misleading tag ID warnings
* Increases maximum size of Blocks inline comments to 140 characters
* Adds Blocks sample BasicOmniOpMode.
* Updated CENTERSTAGE library AprilTag orientation quaternions
    * Thanks [@FromenActual](https://github.com/FromenActual)
* Updated Java Sample ConceptTensorFlowObjectDetection.java to include missing elements needed for custom model support.

### Bug Fixes
* Fixes a problem where after October 1 the Driver Station will report as obsolete on v9.0 and prompt the user to update.

## Version 9.0 (20230830-154348)

### Breaking Changes
* Removes Vuforia
* Fields in `AprilTagDetection` and `AprilTagPose(ftc/raw)` objects are now `final`
* VisionPortal builder method `setCameraMonitorViewId()` has been renamed to `setLiveViewContainerId()` and `enableCameraMonitoring()` has been renamed to `enableLiveView()`

### Enhancements
* Adds support for the DFRobot HuskyLens Vision Sensor.
* Blocks teams can now perform webcam calibration.
    * Added a Block for System.currentTimeMillis (under Utilities/Time)
    * Added a Block for VisionPortal.saveNextFrameRaw (under Vision/VisionPortal)
    * Added a new sample Blocks OpMode called UtilityCameraFrameCapture.
* The RobotDriveByGyro sample has been updated to use the new universal IMU interface.  It now supports both IMU types.
* Removed some error-prone ElapsedTime Blocks from the Blocks editor's toolbox. This is not a
  breaking change: old Blocks OpModes that use these Blocks will still function, both in the
  Blocks editor and at runtime.
* Standardizes on the form "OpMode" for the term OpMode.
    * The preferred way to refer to OpModes that specifically extend `LinearOpMode` (including Blocks OpModes) is "linear OpMode".
    * The preferred way to refer to OpModes that specifically extend `OpMode` directly is "iterative OpMode".
* Overhauls `OpMode` and `LinearOpMode` Javadoc comments to be easier to read and include more detail.
* Makes minor enhancements to Java samples
    * Javadoc comments in samples that could be rendered badly in Android Studio have been converted to standard multi-line comments
    * Consistency between samples has been improved
    * The SensorDigitalTouch sample has been replaced with a new SensorTouch sample that uses the `TouchSensor` interface instead of `DigitalChannel`.
    * The ConceptCompassCalibration, SensorMRCompass, and SensorMRIRSeeker samples have been deleted, as they are not useful for modern FTC competitions.

### Bug Fixes
* Fixes a bug which prevented PlayStation gamepads from being used in bluetooth mode. Bluetooth is NOT legal for competition but may be useful to allow a DS device to be used while charging, or at an outreach event.
* Fixes a bug where a Blocks OpMode's Date Modified value can change to December 31, 1969, if the Control Hub is rebooted while the Blocks OpMode is being edited.
* Fixes the automatic TeleOp preselection feature (was broken in 8.2)
* Fixes a bug where passing an integer number such as 123 to the Telemetry.addData block that takes a number shows up as 123.0 in the telemetry.
* Fixes OnBotJava autocomplete issues:
  * Autocomplete would incorrectly provide values for the current class when autocompleting a local variable
  * `hardwareMap` autocomplete would incorrectly include lambda class entries
* Fixes OnBotJava not automatically importing classes.
* Fixes OnBotJava tabs failing to close when their file is deleted.
* Fixes a project view refresh not happening when a file is renamed in OnBotJava.
* Fixes the "Download" context menu item for external libraries in the OnBotJava interface.
* Fixes issue where Driver Station telemetry would intermittently freeze when set to Monospace mode.
* Fixes performance regression for certain REV Hub operations that was introduced in version 8.2.
* Fixes TagID comparison logic in DriveToTag samples.

## Version 8.2 (20230707-131020)

### Breaking Changes
* Non-linear (iterative) OpModes are no longer allowed to manipulate actuators in their `stop()` method. Attempts to do so will be ignored and logged.
  * When an OpMode attempts to illegally manipulate an actuator, the Robot Controller will print a log message
    including the text `CANCELLED_FOR_SAFETY`.
  * Additionally, LinearOpModes are no longer able to regain the ability to manipulate actuators by removing their
    thread's interrupt or using another thread.
* Removes support for Android version 6.0 (Marshmallow). The minSdkVersion is now 24.
* Increases the Robocol version.
  * This means an 8.2 or later Robot Controller or Driver Station will not be able to communicate with an 8.1 or earlier Driver Station or Robot Controller.
  * If you forget to update both apps at the same time, an error message will be shown explaining which app is older and should be updated.
* FTC_FieldCoordinateSystemDefinition.pdf has been moved.  It is still in the git history, but has been removed from the git snapshot corresponding with the 8.2 tag.  The official version now lives at [Field Coordinate System](https://ftc-docs.firstinspires.org/field-coordinate-system).
* `LynxUsbDevice.addConfiguredModule()` and `LynxUsbDevice.getConfiguredModule()` have been replaced with `LynxUsbDevice.getOrAddModule()`.
* Old Blocks for Vuforia and TensorFlow Object Detection are obsolete and have been removed from the
  Blocks editor's toolbox. Existing Blocks OpModes that contain the old Blocks for Vuforia or
  TensorFlow Object Detection can be opened in the Blocks editor, but running them will not work.

### New features
* Adds new `VisionPortal` API for computer vision
    * **This API may be subject to change for final kickoff release!**
    * Several new samples added.
    * Adds support for detecting AprilTags.
    * `VisionPortal` is the new entry point for both AprilTag and TFOD processing.
    * Vuforia will be removed in a future release.
    * Updated TensorFlow dependencies.
    * Added support for webcam camera controls to blocks.
    * The Blocks editor's toolbox now has a Vision category, directly above the Utilities category.
* Related documentation for associated technologies can be found at
    * [AprilTag Introduction](https://ftc-docs.firstinspires.org/apriltag-intro)
    * [AprilTag SDK Guide](https://ftc-docs.firstinspires.org/apriltag-sdk)
    * [AprilTag Detection Values](https://ftc-docs.firstinspires.org/apriltag-detection-values)
    * [AprilTag Test Images](https://ftc-docs.firstinspires.org/apriltag-test-images)
    * [Camera Calibration](https://ftc-docs.firstinspires.org/camera-calibration)
* Adds Driver Station support for Logitech Dual Action and Sony PS5 DualSense gamepads.
    * This **does not** include support for the Sony PS5 DualSense Edge gamepad.
    * Always refer to Game Manual 1 to determine gamepad legality in competition.
* Adds support for MJPEG payload streaming to UVC driver (external JPEG decompression routine required for use).
* Shows a hint on the Driver Station UI about how to bind a gamepad when buttons are pressed or the sticks are moved on an unbound gamepad.
* Adds option for fullscreening "Camera Stream" on Driver Station.
* OnBotJava source code is automatically saved as a ZIP file on every build with a rolling window of the last 30 builds kept; allows recovering source code from previous builds if code is accidentally deleted or corrupted.
* Adds support for changing the addresses of Expansion Hubs that are not connected directly via USB.
  * The Expansion Hub Address Change screen now has an Apply button that changes the addresses without leaving the screen.
  * Addresses that are assigned to other hubs connected to the same USB connection or Control Hub are no longer able to be selected.
* Increases maximum size of Blocks inline comments to 100 characters
* Saves position of open Blocks comment balloons
* Adds new AprilTag Driving samples:  RobotDriveToAprilTagTank & RobotDriveToAprilTagOmni
* Adds Sample to illustrate optimizing camera exposure for AprilTags: ConceptAprilTagOptimizeExposure

### Bug Fixes
* Corrects inspection screen to report app version using the SDK version defined in the libraries instead of the version specified in `AndroidManifest.xml`. This corrects the case where the app could show matching versions numbers to the user but still state that the versions did not match.
  * If the version specified in `AndroidManifest.xml` does not match the SDK version, an SDK version entry will be displayed on the Manage webpage.
* Fixes no error being displayed when saving a configuration file with duplicate names from the Driver Station.
* Fixes a deadlock in the UVC driver which manifested in https://github.com/OpenFTC/EasyOpenCV/issues/57.
* Fixes a deadlock in the UVC driver that could occur when hot-plugging cameras.
* Fixes UVC driver compatibility with Arducam OV9281 global shutter camera.
* Fixes Emergency Stop condition when an OnBotJava build with duplicate OpMode names occurs.
* Fixes known causes of "Attempted use of a closed LynxModule instance" logspam.
* Fixes the visual identification LED pattern when configuring Expansion Hubs connected via RS-485.

## Version 8.1.1 (20221201-150726)

This is a bug fix only release to address the following four issues.

* [Issue #492](https://github.com/FIRST-Tech-Challenge/FtcRobotController/issues/492) - Can't create new blocks opmodes.
* [Issue #495](https://github.com/FIRST-Tech-Challenge/FtcRobotController/issues/495) - Remove the final modifier from the OpMode's Telemetry object.
* [Issue #500](https://github.com/FIRST-Tech-Challenge/FtcRobotController/issues/500) - Some devices cannot be configured when the Driver Station app has been updated to 8.1
  * Updating either the Robot Controller app or the Driver Station app to 8.1.1 or later will fix this issue.
* The Modern Robotics touch sensor was configurable as a  Digital Device. It can only be used as an Analog Device.

## Version 8.1 (20221121-115119)

### Breaking Changes
* Deprecates the `OpMode` fields `msStuckDetectInit`, `msStuckDetectInitLoop`, `msStuckDetectStart`, `msStuckDetectLoop`, and `msStuckDetectStop`.
    * OpModes no longer have a time limit for `init()`, `init_loop()`, `start()` or `loop()`, so the fields corresponding to those methods are no longer used.
    * `stop()` still has a time limit, but it is now hardcoded to be 1 second, and cannot be changed using `msStuckDetectStop`.
* Deprecates the `OpMode` methods `internalPreInit()`, `internalPostInitLoop()`, and `internalPostLoop()`.
    * Iterative `OpMode`s will continue to call these methods in case they were overridden.
    * These methods will not be called at all for `LinearOpMode`s.
* Deprecates (and stops respecting) `DeviceProperties.xmlTagAliases`.

### Enhancements
* Adds a new `IMU` interface to Blocks and Java that can be used with both the original BNO055 IMU
  included in all older Control Hubs and Expansion Hubs, and the new alternative BHI260AP IMU.
  * You can determine which type of IMU is in your Control Hub by navigating to the Manage page of the web interface.
  * To learn how to use the new `IMU` interface, see https://ftc-docs.firstinspires.org/programming_resources/imu/imu.html. The `SensorIMU` Blocks sample was also updated to use the new `IMU` interface, and the following Java samples were added:
    * `SensorIMUOrthogonal`
      * Use this sample if your REV Hub is mounted so that it is parallel or perpendicular to the
        bottom of your robot.
    * `SensorIMUNonOrthogonal`
      * Use this sample if your REV Hub is mounted to your robot in any other orientation
    * `ConceptExploringIMUOrientations`
      * This OpMode is a tool to help you understand how the orthogonal orientations work, and
        which one applies to your robot.
  * The BHI260AP IMU can only be accessed via the new `IMU` interface. The BNO055 IMU can be
    programmed using the new `IMU` interface, or you can continue to program it using the old `BNO055IMU`
    interface. If you want to be able to quickly switch to a new Control Hub that may contain the
    BHI260AP IMU, you should migrate your code to use the new `IMU` interface.
  * Unlike the old `BNO055IMU` interface, which only worked correctly when the REV Hub was mounted flat
    on your robot, the `IMU` interface allows you to specify the orientation of the REV Hub on your
    robot. It will account for this, and give you your orientation in a Robot Coordinate System,
    instead of a special coordinate system for the REV Hub. As a result, your pitch and yaw will be
    0 when your *robot* is level, instead of when the REV Hub is level, which will result in much
    more reliable orientation angle values for most mounting orientations.
  * Because of the new robot-centric coordinate system, the pitch and roll angles returned by the
    `IMU` interface will be different from the ones returned by the `BNO055IMU` interface. When you are
    migrating your code, pay careful attention to the documentation.
  * If you have calibrated your BNO055, you can provide that calibration data to the new `IMU`
    interface by passing a `BNO055IMUNew.Parameters` instance to `IMU.initialize()`.
  * The `IMU` interface is also suitable for implementation by third-party vendors for IMUs that
    support providing the orientation in the form of a quaternion.
* Iterative `OpMode`s (as opposed to `LinearOpMode`s) now run on a dedicated thread.
    * Cycle times should not be as impacted by everything else going on in the system.
    * Slow `OpMode`s can no longer increase the amount of time it takes to process network commands, and vice versa.
    * The `init()`, `init_loop()`, `start()` and `loop()` methods no longer need to return within a certain time frame.
* BNO055 IMU legacy driver: restores the ability to initialize in one OpMode, and then have another OpMode re-use that
  initialization. This allows you to maintain the 0-yaw position between OpModes, if desired.
* Allows customized versions of device drivers in the FTC SDK to use the same XML tag.
  * Before, if you wanted to customize a device driver, you had to copy it to a new class _and_ give
    it a new XML tag. Giving it a new XML tag meant that to switch which driver was being used, you
    had to modify your configuration file.
  * Now, to use your custom driver, all you have to do is specify your custom driver's class when
    calling `hardwareMap.get()`. To go back to the original driver, specify the original driver
    class. If you specify an interface that is implemented by both the original driver and the
    custom driver, there is no guarantee about which implementation will be returned.

### Bug Fixes
* Fixes accessing the "Manage TensorFlow Lite Models" and "Manage Sounds" links and performing
  Blocks and OnBotJava OpMode downloads from the REV Hardware Client.
* Fixes issue where an I2C device driver would be auto-initialized using the parameters assigned in
  a previous OpMode run.
* Improves Driver Station popup menu placement in the landscape layout.
* Fixes NullPointerException when attempting to get a non-configured BNO055 IMU in a Blocks OpMode on an RC phone.
* Fixes problem with Blocks if a variable is named `orientation`.

## Version 8.0 (20220907-131644)

### Breaking Changes
* Increases the Robocol version.
  * This means an 8.0 or later Robot Controller or Driver Station will not be able to communicate with a 7.2 or earlier Driver Station or Robot Controller.
  * If you forget to update both apps at the same time, an error message will be shown explaining which app is older and should be updated.
* Initializing I2C devices now happens when you retrieve them from the `HardwareMap` for the first time.
  * Previously, all I2C devices would be initialized before the OpMode even began executing,
    whether you were actually going to use them or not. This could result in reduced performance and
    unnecessary warnings.
  * With this change, it is very important for Java users to retrieve all needed devices from the
    `HardwareMap` **during the Init phase of the OpMode**. Namely, declare a variable for each hardware
    device the OpMode will use, and assign a value to each. Do not do this during the Run phase, or your
    OpMode may briefly hang while the devices you are retrieving get initialized.
  * OpModes that do not use all of the I2C devices specified in the configuration file should take
    less time to initialize. OpModes that do use all of the specified I2C devices should take the
    same amount of time as previously.
* Fixes [issue #251](https://github.com/FIRST-Tech-Challenge/FtcRobotController/issues/251) by changing the order in which axis rotation rates are read from the angular velocity vector in the BNO055 IMU driver.
* Deprecates `pitchMode` in `BNO055IMU.Parameters`.
  * Setting `pitchMode` to `PitchMode.WINDOWS` would break the coordinate conventions used by the driver.
* Moves `OpModeManagerImpl` to the `com.qualcomm.robotcore.eventloop.opmode` package.
  * This breaks third party libraries EasyOpenCV (version 1.5.1 and earlier) and FTC Dashboard (version 0.4.4 and earlier).
* Deletes the deprecated `OpMode` method `resetStartTime()` (use `resetRuntime()` instead).
* Deletes the protected `LinearOpMode.LinearOpModeHelper` class (which was not meant for use by OpModes).
* Removes I2C Device (Synchronous) config type (deprecated since 2018)

### Enhancements
* Uncaught exceptions in OpModes no longer require a Restart Robot
  * A blue screen popping up with a stacktrace is not an SDK error; this replaces the red text in the telemetry area.
  * Since the very first SDK release, OpMode crashes have put the robot into "EMERGENCY STOP" state, only showing the first line of the exception, and requiring the user to press "Restart Robot" to continue
  * Exceptions during an OpMode now open a popup window with the same color scheme as the log viewer, containing 15 lines of the exception stacktrace to allow easily tracing down the offending line without needing to connect to view logs over ADB or scroll through large amounts of logs in the log viewer.
  * The exception text in the popup window is both zoomable and scrollable just like a webpage.
  * Pressing the "OK" button in the popup window will return to the main screen of the Driver Station and allow an OpMode to be run again immediately, without the need to perform a "Restart Robot"
* Adds new Java sample to demonstrate using a hardware class to abstract robot actuators, and share them across multiple OpModes.
  * Sample OpMode is [ConceptExternalHardwareClass.java](FtcRobotController/src/main/java/org/firstinspires/ftc/robotcontroller/external/samples/ConceptExternalHardwareClass.java)
  * Abstracted hardware class is [RobotHardware.java](FtcRobotController/src/main/java/org/firstinspires/ftc/robotcontroller/external/samples/RobotHardware.java)
* Updates RobotAutoDriveByGyro_Linear Java sample to use REV Control/Expansion hub IMU.
* Updates Vuforia samples to reference PowerPlay assets and have correct names and field locations of image targets.
* Updates TensorFlow samples to reference PowerPlay assets.
* Adds opt-in support for Java 8 language features to the OnBotJava editor.
  * To opt in, open the OnBotJava Settings, and check `Enable beta Java 8 support`.
  * Note that Java 8 code will only compile when the Robot Controller runs Android 7.0 Nougat or later.
  * Please report issues [here](https://github.com/FIRST-Tech-Challenge/FtcRobotController/issues).
* In OnBotJava, clicking on build errors now correctly jumps to the correct location.
* Improves OnBotJava autocomplete behavior, to provide better completion options in most cases.
* Adds a QR code to the Robot Controller Inspection Report when viewed from the Driver Station for scanning by inspectors at competition.
* Improves I2C performance and reliability in some scenarios.

## Version 7.2 (20220723-130006)

### Breaking Changes
* Updates the build tooling.  For Android Studio users, this change requires Android Studio Chipmunk 2021.2.1.
* Removes support for devices that are not competition legal, including Modern Robotics Core Control Modules, the Matrix Controller, and HiTechnic/NXT controllers and sensors.  Support remains for Modern Robotics I2C sensors.

### Enhancements
* Increases the height of the 3-dots Landscape menu touch area on the Driver Station, making it much easier to select.
* Adds `terminateOpModeNow()` method to allow OpModes to cleanly self-exit immediately.
* Adds `opModeInInit()` method to `LinearOpMode` to facilitate init-loops. Similar to `opModeIsActive()` but for the init phase.
* Warns user if they have a Logitech F310 gamepad connected that is set to DirectInput mode.
* Allows SPARKmini motor controllers to react more quickly to speed changes.
* Hides the version number of incorrectly installed sister app (i.e. DS installed on RC device or vice-versa) on inspection screen.
* Adds support for allowing the user to edit the comment for the runOpMode block.
* Adds parameterDefaultValues field to @ExportToBlocks. This provides the ability for a java method with an @ExportToBlocks annotation to specify default values for method parameters when it is shown in the block editor.
* Make LinearOpMode blocks more readable. The opmode name is displayed on the runOpMode block, but not on the other LinearOpMode blocks.
* Added support to TensorFlow Object Detection for using a different frame generator, instead of Vuforia.
  Using Vuforia to pass the camera frame to TFOD is still supported.
* Removes usage of Renderscript.
* Fixes logspam on app startup of repeated stacktraces relating to `"Failed resolution of: Landroid/net/wifi/p2p/WifiP2pManager$DeviceInfoListener"`
* Allows disabling bluetooth radio from inspection screen
* Improves warning messages when I2C devices are not responding
* Adds support for controlling the RGB LED present on PS4/Etpark gamepads from OpModes
* Removes legacy Pushbot references from OpMode samples.  Renames "Pushbot" samples to "Robot".  Motor directions reversed to be compatible with "direct Drive" drive train.

### Bug fixes
* Fixes [issue #316](https://github.com/FIRST-Tech-Challenge/FtcRobotController/issues/316) (MatrixF.inverted() returned an incorrectly-sized matrix for 1x1 and 2x2 matrixes).
* Self inspect now allows for Driver Station and Robot Controller compatibility between point releases.
* Fixes bug where if the same `RumbleEffect` object instance was queued for multiple gamepads, it
  could happen that both rumble commands would be sent to just one gamepad.
* Fixes bug in Driver Station where on the Driver Hub, if Advanced Gamepad Features was disabled and
  an officially supported gamepad was connected, then opening the Advanced Gamepad Features or
  Gamepad Type Overrides screens would cause the gamepad to be rebound by the custom USB driver even
  though advanced gamepad features was disabled.
* Protects against (unlikely) null pointer exception in Vuforia Localizer.
* Harden OnBotJava and Blocks saves to protect against save issues when disconnecting from Program and Manage
* Fixes issue where the RC app would hang if a REV Hub I2C write failed because the previous I2C
  operation was still in progress. This hang most commonly occurred during REV 2M Distance Sensor initialization
* Removes ConceptWebcam.java sample program.  This sample is not compatible with OnBotJava.
* Fixes bug where using html tags in an @ExportToBlocks comment field prevented the blocks editor from loading.
* Fixes blocks editor so it doesn't ask you to save when you haven't modified anything.
* Fixes uploading a very large blocks project to offline blocks editor.
* Fixes bug that caused blocks for DcMotorEx to be omitted from the blocks editor toolbox.
* Fixes [Blocks Programs Stripped of Blocks (due to using TensorFlow Label block)](https://ftcforum.firstinspires.org/forum/ftc-technology/blocks-programming/87035-blocks-programs-stripped-of-blocks)

## Version 7.1 (20211223-120805)

* Fixes crash when calling `isPwmEnabled()` ([issue #223](https://github.com/FIRST-Tech-Challenge/FtcRobotController/issues/233)).
* Fixes lint error ([issue #4](https://github.com/FIRST-Tech-Challenge/FtcRobotController/issues/4)).
* Fixes Driver Station crash when attempting to use DualShock4 v1 gamepad with Advanced Gamepad Features enabled ([issue #173](https://github.com/FIRST-Tech-Challenge/FtcRobotController/issues/173)).
* Fixes possible (but unlikely) Driver Station crash when connecting gamepads of any type.
* Fixes bug where Driver Station would use generic 20% deadzone for Xbox360 and Logitech F310 gamepads when Advanced Gamepad Features was disabled.
* Added SimpleOmniDrive sample OpMode.
* Adds UVC white balance control API.
* Fixes [issue #259](https://github.com/FIRST-Tech-Challenge/FtcRobotController/issues/259) Most blocks samples for TensorFlow can't be used for a different model.
    * The blocks previously labeled TensorFlowObjectDetectionFreightFrenzy (from the subcategory named "Optimized for Freight Frenzy") and TensorFlowObjectDetectionCustomModel (from the subcategory named "Custom Model") have been replaced with blocks labeled TensorFlowObjectDetection. Blocks in existing opmodes will be automatically updated to the new blocks when opened in the blocks editor.
* Fixes [issue #260](https://github.com/FIRST-Tech-Challenge/FtcRobotController/issues/260) Blocks can't call java method that has a VuforiaLocalizer parameter.
    * Blocks now has a block labeled VuforiaFreightFrenzy.getVuforiaLocalizer for this.
* Added a page to manage the TensorFlow Lite models in /sdcard/FIRST/tflitemodels. To get to the TFLite Models page:
    * You can click on the link at the bottom of the Manage page.
    * You can click on the link at the upper-right the Blocks project page.
* Fixes logspam when `isBusy()` is called on a motor not in RTP mode.
* Hides the "RC Password" item on the inspection screen for phone-based Robot Controllers. (It is only applicable for Control Hubs).
* Adds channel 165 to Wi-Fi Direct channel selection menu in the settings screen. (165 was previously available through the web UI, but not locally in the app).

## Version 7.0 (20210915-141025)

### Enhancements and New Features
* Adds support for external libraries to OnBotJava and Blocks.
    * Upload .jar and .aar files in OnBotJava.
      * Known limitation - RobotController device must be running Android 7.0 or greater.
      * Known limitation - .aar files with assets are not supported.
    * External libraries can provide support for hardware devices by using the annotation in the
      com.qualcomm.robotcore.hardware.configuration.annotations package.
    * External libraries can include .so files for native code.
    * External libraries can be used from OnBotJava OpModes.
    * External libraries that use the following annotations can be used from Blocks OpModes.
      * org.firstinspires.ftc.robotcore.external.ExportClassToBlocks
      * org.firstinspires.ftc.robotcore.external.ExportToBlocks
    * External libraries that use the following annotations can add new hardware devices:
      * com.qualcomm.robotcore.hardware.configuration.annotations.AnalogSensorType
      * com.qualcomm.robotcore.hardware.configuration.annotations.DeviceProperties
      * com.qualcomm.robotcore.hardware.configuration.annotations.DigitalIoDeviceType
      * com.qualcomm.robotcore.hardware.configuration.annotations.I2cDeviceType
      * com.qualcomm.robotcore.hardware.configuration.annotations.MotorType
      * com.qualcomm.robotcore.hardware.configuration.annotations.ServoType
    * External libraries that use the following annotations can add new functionality to the Robot Controller:
      * org.firstinspires.ftc.ftccommon.external.OnCreate
      * org.firstinspires.ftc.ftccommon.external.OnCreateEventLoop
      * org.firstinspires.ftc.ftccommon.external.OnCreateMenu
      * org.firstinspires.ftc.ftccommon.external.OnDestroy
      * org.firstinspires.ftc.ftccommon.external.WebHandlerRegistrar
* Adds support for REV Robotics Driver Hub.
* Adds fully custom userspace USB gamepad driver to Driver Station (see "Advanced Gamepad Features" menu in DS settings).
    * Allows gamepads to work on devices without native Linux kernel support (e.g. some Romanian Motorola devices).
    * Allows the DS to read the unique serial number of each gamepad, enabling auto-recovery of dropped gamepads even if two gamepads of the same model drop. *(NOTE: unfortunately this does not apply to Etpark gamepads, because they do not have a unique serial)*.
    * Reading the unique serial number also provides the ability to configure the DS to assign gamepads to a certain position by default (so no need to do start+a/b at all).
    * The LED ring on the Xbox360 gamepad and the RGB LED bar on the PS4 gamepad is used to indicate the driver position the gamepad is bound to.
    * The rumble motors on the Xbox360, PS4, and Etpark gamepads can be controlled from OpModes.
    * The 2-point touchpad on the PS4 gamepad can be read from OpModes.
    * The "back" and "guide" buttons on the gamepad can now be safely bound to robot controls (Previously, on many devices, Android would intercept these buttons as home button presses and close the app).
    * Advanced Gamepad features are enabled by default, but may be disabled through the settings menu in order to revert to gamepad support provided natively by Android.
* Improves accuracy of ping measurement.
    * Fixes issue where the ping time showed as being higher than reality when initially connecting to or restarting the robot.
    * To see the full improvement, you must update both the Robot Controller and Driver Station apps.
* Updates samples located at [/FtcRobotController/src/main/java/org/firstinspires/ftc/robotcontroller/external/samples](FtcRobotController/src/main/java/org/firstinspires/ftc/robotcontroller/external/samples).
    * Added ConceptGamepadRumble and ConceptGamepadTouchpad samples to illustrate the use of these new gampad capabilities.
    * Condensed existing Vuforia samples into just 2 samples (ConceptVuforiaFieldNavigation & ConceptVuforiaFieldNavigationWebcam) showing how to determine the robot's location on the field using Vuforia. These both use the current season's Target images.
    * Added ConceptVuforiaDriveToTargetWebcam to illustrate an easy way to drive directly to any visible Vuforia target.
* Makes many improvements to the warning system and individual warnings.
    * Warnings are now much more spaced out, so that they are easier to read.
    * New warnings were added for conditions that should be resolved before competing.
    * The mismatched apps warning now uses the major and minor app versions, not the version code.
    * The warnings are automatically re-enabled when a Robot Controller app from a new FTC season is installed.
* Adds support for I2C transactions on the Expansion Hub / Control Hub without specifying a register address.
    * See section 3 of the [TI I2C spec](https://www.ti.com/lit/an/slva704/slva704.pdf).
    * Calling these new methods when using Modern Robotics hardware will result in an UnsupportedOperationException.
* Changes VuforiaLocalizer `close()` method to be public.
* Adds support for TensorFlow v2 object detection models.
* Reduces ambiguity of the Self Inspect language and graphics.
* OnBotJava now warns about potentially unintended file overwrites.
* Improves behavior of the Wi-Fi band and channel selector on the Manage webpage.

### Bug fixes
 * Fixes Robot Controller app crash on Android 9+ when a Driver Station connects.
 * Fixes issue where an OpMode was responsible for calling shutdown on the
   TensorFlow TFObjectDetector. Now this is done automatically.
 * Fixes Vuforia initialization blocks to allow user to chose AxesOrder. Updated
   relevant blocks sample opmodes.
 * Fixes [FtcRobotController issue #114](https://github.com/FIRST-Tech-Challenge/FtcRobotController/issues/114)
   LED blocks and Java class do not work.
 * Fixes match logging for OpModes that contain special characters in their names.
 * Fixes Driver Station OpMode controls becoming unresponsive if the Driver Station was set to the landscape layout and an OnBotJava build was triggered while an OpMode was running.
 * Fixes the Driver Station app closing itself when it is switched away from, or the screen is turned off.
 * Fixes "black swirl of doom" (Infinite "configuring Wi-Fi Direct" message) on older devices.
 * Updates the wiki comment on the OnBotJava intro page.

## Version 6.2 (20210218-074821)

### Enhancements
* Attempts to automatically fix the condition where a Control Hub's internal Expansion Hub is not
  working by re-flashing its firmware
* Makes various improvements to the Wi-Fi Direct pairing screen, especially in landscape mode
* Makes the Robot Controller service no longer be categorically restarted when the main activity is brought to foreground
    * (e.g. the service is no longer restarted simply by viewing the Self Inspect screen and pressing the back button)
    * It is still restarted if the Settings menu or Configure Robot menu is opened

### Bug fixes
* Fixes [FtcRobotController issue #71](https://github.com/FIRST-Tech-Challenge/FtcRobotController/issues/71)
  Cannot open OpModes in v6.1 Blocks offline editor
* Fixes [FtcRobotController issue #79](https://github.com/FIRST-Tech-Challenge/FtcRobotController/issues/79)
  6.1 causes a soft reboot on the Motorola E5 Play
* Fixes issue where the Control Hub OS's watchdog would restart the Robot Controller app if
  the Control Hub was not able to communicate with its internal Expansion Hub
* Fixes certain I2C devices not showing up in the appropriate `HardwareMap` fields (such as `hardwareMap.colorSensor`)
* Fixes issue where performing a Wi-Fi factory reset on the Control Hub would not set the Wi-Fi band to 2.4 GHz
* Fixes issue where OnBotJava might fail to create a new file if the option to "Setup Code for Configured Hardware" was selected
* Fixes issue where performing certain operations after an OpMode crashes would temporarily break Control/Expansion Hub communication
* Fixes issue where a Control Hub with a configured USB-connected Expansion Hub would not work if the Expansion Hub was missing at startup
* Fixes potential issues caused by having mismatched Control/Expansion Hub firmware versions
* Fixes [ftc_app issue 673](https://github.com/ftctechnh/ftc_app/issues/673) Latest matchlog is being deleted instead of old ones by RobotLog
* Fixes ConceptVuforiaUltimateGoalNavigationWebcam sample opmode by correctly orienting camera on robot.
* Fixes issue where logcat would be spammed with InterruptedExceptions when stop is requested from the Driver Station (this behavior was accidentally introduced in v5.3). This change has no impact on functionality.
* Fixes issue where the blocks editor fails to load if the name of any TeleOp opmode contains an apostrophe.

## Version 6.1 (20201209-113742)
* Makes the scan button on the configuration screen update the list of Expansion Hubs connected via RS-485
    * Fixes [SkyStone issue #143](https://github.com/FIRST-Tech-Challenge/SkyStone/issues/143)
* Improves web interface compatibility with older browser and Android System WebView versions.
* Fixes issue in UVC driver where some cameras (e.g. certain MS Lifecams) which reported frame intervals as rounded rather than truncated values (e.g. `666667*100ns` instead of `666666*100ns` for 15FPS) would fail to start streaming.
* Adds support in UVC driver for virtual PTZ control
* Adds support in UVC driver for gain (ISO) control
* Adds support in UVC driver for enabling/disable AE priority. This setting provides a means to tell the camera firmware either
    * A) It can undershoot the requested frame rate in order to provide a theoretically better image (i.e. with a longer exposure than the inter-frame period of the selected frame rate allows)
    * B) It *must* meet the inter-frame deadline for the selected frame rate, even if the image may be underexposed as a result
* Adds support for the Control Hub OS 1.1.2 Robot Controller watchdog
    * The Robot Controller app will be restarted if it stops responding for more than 10 seconds
* Adds support for using the Driver Station app on Android 10+
* Introduces an automatic TeleOp preselection feature
    * For details and usage guide, please see [this wiki entry](https://github.com/FIRST-Tech-Challenge/FtcRobotController/wiki/Automatically-Loading-a-Driver-Controlled-Op-Mode)
* Shows icon next to OpMode name in the OpMode list dropdown on the Driver Station to indicate the source of the OpMode (i.e. the programming tool used to create it)
* Fixes issue where the Driver Station app would exit after displaying the Configuring Wi-Fi Direct screen
* Fixes Blocks and OnBotJava prompts when accessed via the REV Hardware Client

## Version 6.0 (20200921-085816)

### Important Notes
* Version 6.0 is the version for the Ultimate Goal season.
* Requires Android Studio 4.0.
* Android Studio users need to be connected to the Internet the first time they build the app (in order to download needed packages for the build).
* Version 5.5 was a moderately large off-season, August 2020, drop.  It's worth reviewing those release notes below also.
* Version 5.5 and greater will not work on older Android 4.x and 5.x phones.  Users must upgrade to an approved Android 6.x device or newer.
* The default PIDF values for REV motors have been reverted to the default PID values that were used in the 2018-2019 season
    * This change was made because the 2018-2019 values turned out to work better for many mechanisms
    * This brings the behavior of the REV motors in line with the behavior of all other motors
    * If you prefer the 2019-2020 season's behavior for REV motors, here are the PIDF values that were in place, so that you can manually set them in your OpModes:
      <br>
      **HD Hex motors (all gearboxes):**
      Velocity PIDF values: `P = 1.17`, `I = 0.117`, `F = 11.7`
      Position PIDF values: `P = 5.0`
      **Core Hex motor:**
      Velocity PIDF values: `P = 4.96`, `I = 0.496`, `F = 49.6`
      Position PIDF values: `P = 5.0`

### New features
* Includes TensorFlow inference model and sample OpModes to detect Ultimate Goal Starter Stacks (four rings vs single ring stack).
* Includes Vuforia Ultimate Goal vision targets and sample OpModes.
* Introduces a digital zoom feature for TensorFlow object detection (to detect objects more accurately at greater distances).
* Adds configuration entry for the REV UltraPlanetary HD Hex motor

### Enhancements
* Adds setGain() and getGain() methods to the NormalizedColorSensor interface
    * By setting the gain of a color sensor, you can adjust for different lighting conditions.
      For example, if you detect lower color values than expected, you can increase the gain.
    * The gain value is only applied to the argb() and getNormalizedColors() methods, not to the raw color methods.
      The getNormalizedColors() method is recommended for ease-of-use and clarity, since argb() has to be converted.
    * Updates SensorColor Java sample to demonstrate gain usage
* Merges SensorREVColorDistance Java sample into SensorColor Java sample, which showcases best practices for all color sensors
* Improves retrieving values from the REV Color Sensor V3
    * Updates the normalization calculation of the RGB channels
    * Improves the calculation of the alpha channel (can be used as an overall brightness indicator)
    * Fixes the default sensor resolution, which caused issues with bright environments
    * Adds support for changing the resolution and measuring rate of the Broadcom sensor chip
    * Removes IR readings and calculations not meant for the Broadcom sensor chip

### Bug fixes
* Improves reliability of BNO055IMU IMU initialization to prevent random initialization failures (which manifested as `Problem with 'imu'`).

## Version 5.5 (20200824-090813)

Version 5.5 requires Android Studio 4.0 or later.

### New features
* Adds support for calling custom Java classes from Blocks OpModes (fixes [SkyStone issue #161](https://github.com/FIRST-Tech-Challenge/SkyStone/issues/161)).
    * Classes must be in the org.firstinspires.ftc.teamcode package.
    * To have easy access to the opMode, hardwareMap, telemetry, gamepad1, and gamepad2, classes can
      extends org.firstinspires.ftc.robotcore.external.BlocksOpModeCompanion.
    * Methods must be public static and have no more than 21 parameters.
    * Methods must be annotated with org.firstinspires.ftc.robotcore.external.ExportToBlocks.
    * Parameters declared as OpMode, LinearOpMode, Telemetry, and HardwareMap are supported and the
      argument is provided automatically, regardless of the order of the parameters. On the block,
      the sockets for those parameters are automatically filled in.
    * Parameters declared as char or java.lang.Character will accept any block that returns text
      and will only use the first character in the text.
    * Parameters declared as boolean or java.lang.Boolean will accept any block that returns boolean.
    * Parameters declared as byte, java.lang.Byte, short, java.lang.Short, int, java.lang.Integer,
      long, or java.lang.Long,  will accept any block that returns a number and will round that
      value to the nearest whole number.
    * Parameters declared as float, java.lang.Float, double, java.lang.Double will accept any
      block that returns a number.
* Adds telemetry API method for setting display format
    * Classic
    * Monospace
    * HTML (certain tags only)
* Adds blocks support for switching cameras.
* Adds Blocks support for TensorFlow Object Detection with a custom model.
* Adds support for uploading a custom TensorFlow Object Detection model in the Manage page, which
  is especially useful for Blocks and OnBotJava users.
* Shows new Control Hub blink codes when the Wi-Fi band is switched using the Control Hub's button (only possible on Control Hub OS 1.1.2)
* Adds new warnings which can be disabled in the Advanced RC Settings
    * Mismatched app versions warning
    * Unnecessary 2.4 GHz Wi-Fi usage warning
    * REV Hub is running outdated firmware (older than version 1.8.2)
* Adds support for Sony PS4 gamepad, and reworks how gamepads work on the Driver Station
    * Removes preference which sets gamepad type based on driver position. Replaced with menu which allows specifying type for gamepads with unknown VID and PID
	* Attempts to auto-detect gamepad type based on USB VID and PID
	* If gamepad VID and PID is not known, use type specified by user for that VID and PID
	* If gamepad VID and PID is not known AND the user has not specified a type for that VID and PID, an educated guess is made about how to map the gamepad
* Driver Station will now attempt to automatically recover from a gamepad disconnecting, and re-assign it to the position it was assigned to when it dropped
    * If only one gamepad is assigned and it drops: it can be recovered
    * If two gamepads are assigned, and have **different** VID/PID signatures, and only one drops: it will be recovered
    * If two gamepads are assigned, and have **different** VID/PID signatures, and BOTH drop: both will be recovered
    * If two gamepads are assigned, and have **the same** VID/PID signatures, and only one drops: it will be recovered
    * If two gamepads are assigned, and have **the same** VID/PID signatures, and BOTH drop: **neither** will be recovered, because of the ambiguity of the gamepads when they re-appear on the USB bus.
    * There is currently one known edge case: if there are **two** gamepads with **the same** VID/PID signature plugged in, **but only one is assigned**, and they BOTH drop, it's a 50-50 chance of which one will be chosen for automatic recovery to the assigned position: it is determined by whichever one is re-enumerated first by the USB bus controller.
* Adds landscape user interface to Driver Station
    * New feature: practice timer with audio cues
    * New feature (Control Hub only): wireless network connection strength indicator (0-5 bars)
    * New feature (Control Hub only): tapping on the ping/channel display will switch to an alternate display showing radio RX dBm and link speed (tap again to switch back)
    * The layout will NOT autorotate. You can switch the layout from the Driver Station's settings menu.
### Breaking changes
* Removes support for Android versions 4.4 through 5.1 (KitKat and Lollipop). The minSdkVersion is now 23.
* Removes the deprecated `LinearOpMode` methods `waitOneFullHardwareCycle()` and `waitForNextHardwareCycle()`
### Enhancements
* Handles RS485 address of Control Hub automatically
    * The Control Hub is automatically given a reserved address
    * Existing configuration files will continue to work
    * All addresses in the range of 1-10 are still available for Expansion Hubs
    * The Control Hub light will now normally be solid green, without blinking to indicate the address
    * The Control Hub will not be shown on the Expansion Hub Address Change settings page
* Improves REV Hub firmware updater
    * The user can now choose between all available firmware update files
    * Version 1.8.2 of the REV Hub firmware is bundled into the Robot Controller app.
    * Text was added to clarify that Expansion Hubs can only be updated via USB.
    * Firmware update speed was reduced to improve reliability
    * Allows REV Hub firmware to be updated directly from the Manage webpage
* Improves log viewer on Robot Controller
    * Horizontal scrolling support (no longer word wrapped)
    * Supports pinch-to-zoom
    * Uses a monospaced font
    * Error messages are highlighted
    * New color scheme
* Attempts to force-stop a runaway/stuck OpMode without restarting the entire app
    * Not all types of runaway conditions are stoppable, but if the user code attempts to talk to hardware during the runaway, the system should be able to capture it.
* Makes various tweaks to the Self Inspect screen
    * Renames "OS version" entry to "Android version"
    * Renames "Wi-Fi Direct Name" to "Wi-Fi Name"
    * Adds Control Hub OS version, when viewing the report of a Control Hub
    * Hides the airplane mode entry, when viewing the report of a Control Hub
    * Removes check for ZTE Speed Channel Changer
    * Shows firmware version for **all** Expansion and Control Hubs
* Reworks network settings portion of Manage page
    * All network settings are now applied with a single click
    * The Wi-Fi Direct channel of phone-based Robot Controllers can now be changed from the Manage page
    * Wi-Fi channels are filtered by band (2.4 vs 5 GHz) and whether they overlap with other channels
    * The current Wi-Fi channel is pre-selected on phone-based Robot Controllers, and Control Hubs running OS 1.1.2 or later.
    * On Control Hubs running OS 1.1.2 or later, you can choose to have the system automatically select a channel on the 5 GHz band
* Improves OnBotJava
    * New light and dark themes replace the old themes (chaos, github, chrome,...)
        * the new default theme is `light` and will be used when you first update to this version
    * OnBotJava now has a tabbed editor
    * Read-only offline mode
* Improves function of "exit" menu item on Robot Controller and Driver Station
    * Now guaranteed to be fully stopped and unloaded from memory
* Shows a warning message if a LinearOpMode exists prematurely due to failure to monitor for the start condition
* Improves error message shown when the Driver Station and Robot Controller are incompatible with each other
* Driver Station OpMode Control Panel now disabled while a Restart Robot is in progress
* Disables advanced settings related to Wi-Fi Direct when the Robot Controller is a Control Hub.
* Tint phone battery icons on Driver Station when low/critical.
* Uses names "Control Hub Portal" and "Control Hub" (when appropriate) in new configuration files
* Improve I2C read performance
    * Very large improvement on Control Hub; up to ~2x faster with small (e.g. 6 byte) reads
    * Not as apparent on Expansion Hubs connected to a phone
* Update/refresh build infrastructure
    * Update to 'androidx' support library from 'com.android.support:appcompat', which is end-of-life
    * Update targetSdkVersion and compileSdkVersion to 28
    * Update Android Studio's Android plugin to latest
    * Fix reported build timestamp in 'About' screen
* Add sample illustrating manual webcam use: ConceptWebcam

### Bug fixes
* Fixes [SkyStone issue #248](https://github.com/FIRST-Tech-Challenge/SkyStone/issues/248)
* Fixes [SkyStone issue #232](https://github.com/FIRST-Tech-Challenge/SkyStone/issues/232) and
  modifies bulk caching semantics to allow for cache-preserving MANUAL/AUTO transitions.
* Improves performance when REV 2M distance sensor is unplugged
* Improves readability of Toast messages on certain devices
* Allows a Driver Station to connect to a Robot Controller after another has disconnected
* Improves generation of fake serial numbers for UVC cameras which do not provide a real serial number
    * Previously some devices would assign such cameras a serial of `0:0` and fail to open and start streaming
	* Fixes [ftc_app issue #638](https://github.com/ftctechnh/ftc_app/issues/638).
* Fixes a slew of bugs with the Vuforia camera monitor including:
    * Fixes bug where preview could be displayed with a wonky aspect ratio
    * Fixes bug where preview could be cut off in landscape
    * Fixes bug where preview got totally messed up when rotating phone
    * Fixes bug where crosshair could drift off target when using webcams
* Fixes issue in UVC driver on some devices ([ftc_app 681](https://github.com/ftctechnh/ftc_app/issues/681)) if streaming was started/stopped multiple times in a row
    * Issue manifested as kernel panic on devices which do not have [this kernel patch](https://lore.kernel.org/patchwork/patch/352400/).
    * On affected devices which **do** have the patch, the issue was manifest as simply a failure to start streaming.
    * The Tech Team believes that the root cause of the issue is a bug in the Linux kernel XHCI driver. A workaround was implemented in the SDK UVC driver.
* Fixes bug in UVC driver where often half the frames from the camera would be dropped (e.g. only 15FPS delivered during a streaming session configured for 30FPS).
* Fixes issue where TensorFlow Object Detection would show results whose confidence was lower than
  the minimum confidence parameter.
* Fixes a potential exploitation issue of [CVE-2019-11358](https://www.cvedetails.com/cve/CVE-2019-11358/) in OnBotJava
* Fixes changing the address of an Expansion Hub with additional Expansion Hubs connected to it
* Preserves the Control Hub's network connection when "Restart Robot" is selected
* Fixes issue where device scans would fail while the Robot was restarting
* Fix RenderScript usage
    * Use androidx.renderscript variant: increased compatibility
    * Use RenderScript in Java mode, not native: simplifies build
* Fixes webcam-frame-to-bitmap conversion problem: alpha channel wasn't being initialized, only R, G, & B
* Fixes possible arithmetic overflow in Deadline
* Fixes deadlock in Vuforia webcam support which could cause 5-second delays when stopping OpMode

## Version 5.4 (20200108-101156)
* Fixes [SkyStone issue #88](https://github.com/FIRST-Tech-Challenge/SkyStone/issues/88)
* Adds an inspection item that notes when a robot controller (Control Hub) is using the factory default password.
* Fixes [SkyStone issue #61](https://github.com/FIRST-Tech-Challenge/SkyStone/issues/61)
* Fixes [SkyStone issue #142](https://github.com/FIRST-Tech-Challenge/SkyStone/issues/142)
* Fixes [ftc_app issue #417](https://github.com/ftctechnh/ftc_app/issues/417) by adding more current and voltage monitoring capabilities for REV Hubs.
* Fixes [a crash sometimes caused by OnBotJava activity](https://ftcforum.firstinspires.org/forum/ftc-technology/76217-onbotjava-crashes-robot-controller)
* Improves OnBotJava autosave functionality [ftc_app #738](https://github.com/ftctechnh/ftc_app/issues/738)
* Fixes system responsiveness issue when an Expansion Hub is disconnected
* Fixes issue where IMU initialization could prevent OpModes from stopping
* Fixes issue where AndroidTextToSpeech.speak() would fail if it was called too early
* Adds telemetry.speak() methods and blocks, which cause the Driver Station (if also updated) to speak text
* Adds and improves Expansion Hub-related warnings
    * Improves Expansion Hub low battery warning
        * Displays the warning immediately after the hub reports it
        * Specifies whether the condition is current or occurred temporarily during an OpMode run
        * Displays which hubs reported low battery
    * Displays warning when hub loses and regains power during an OpMode run
        * Fixes the hub's LED pattern after this condition
    * Displays warning when Expansion Hub is not responding to commands
        * Specifies whether the condition is current or occurred temporarily during an OpMode run
    * Clarifies warning when Expansion Hub is not present at startup
        * Specifies that this condition requires a Robot Restart before the hub can be used.
        * The hub light will now accurately reflect this state
    * Improves logging and reduces log spam during these conditions
* Syncs the Control Hub time and timezone to a connected web browser programming the robot, if a Driver Station is not available.
* Adds bulk read functionality for REV Hubs
  * A bulk caching mode must be set at the Hub level with `LynxModule#setBulkCachingMode()`. This applies to all relevant SDK hardware classes that reference that Hub.
  * The following following Hub bulk caching modes are available:
    * `BulkCachingMode.OFF` (default): All hardware calls operate as usual. Bulk data can read through `LynxModule#getBulkData()` and processed manually.
    * `BulkCachingMode.AUTO`: Applicable hardware calls are served from a bulk read cache that is cleared/refreshed automatically to ensure identical commands don't hit the same cache. The cache can also be cleared manually with `LynxModule#clearBulkCache()`, although this is not recommended.
    * (advanced users) `BulkCachingMode.MANUAL`: Same as `BulkCachingMode.AUTO` except the cache is never cleared automatically. To avoid getting stale data, the cache must be manually cleared at the beginning of each loop body or as the user deems appropriate.
* Removes PIDF Annotation values added in Rev 5.3 (to AndyMark, goBILDA and TETRIX motor configurations).
  * The new motor types will still be available but their Default control behavior will revert back to Rev 5.2
* Adds new `ConceptMotorBulkRead` sample Opmode to demonstrate and compare Motor Bulk-Read modes for reducing I/O latencies.

## Version 5.3 (20191004-112306)
* Fixes external USB/UVC webcam support
* Makes various bugfixes and improvements to Blocks page, including but not limited to:
    * Many visual tweaks
    * Browser zoom and window resize behave better
    * Resizing the Java preview pane works better and more consistently across browsers
    * The Java preview pane consistently gets scrollbars when needed
    * The Java preview pane is hidden by default on phones
    * Internet Explorer 11 should work
    * Large dropdown lists display properly on lower res screens
    * Disabled buttons are now visually identifiable as disabled
    * A warning is shown if a user selects a TFOD sample, but their device is not compatible
    * Warning messages in a Blocks OpMode are now visible by default.
* Adds goBILDA 5201 and 5202 motors to Robot Configurator
* Adds PIDF Annotation values to AndyMark, goBILDA and TETRIX motor configurations.
    This has the effect of causing the RUN_USING_ENCODERS and RUN_TO_POSITION modes to use
    PIDF vs PID closed loop control on these motors.  This should provide more responsive, yet stable, speed control.
    PIDF adds Feedforward control to the basic PID control loop.
    Feedforward is useful when controlling a motor's speed because it "anticipates" how much the control voltage
    must change to achieve a new speed set-point, rather than requiring the integrated error to change sufficiently.
    The PIDF values were chosen to provide responsive, yet stable, speed control on a lightly loaded motor.
    The more heavily a motor is loaded (drag or friction), the more noticable the PIDF improvement will be.
* Fixes startup crash on Android 10
* Fixes [ftc_app issue #712](https://github.com/ftctechnh/ftc_app/issues/712) (thanks to FROGbots-4634)
* Fixes [ftc_app issue #542](https://github.com/ftctechnh/ftc_app/issues/542)
* Allows "A" and lowercase letters when naming device through RC and DS apps.

## Version 5.2 (20190905-083277)
* Fixes extra-wide margins on settings activities, and placement of the new configuration button
* Adds Skystone Vuforia image target data.
   * Includes sample Skystone Vuforia Navigation OpModes (Java).
   * Includes sample Skystone Vuforia Navigation OpModes (Blocks).
* Adds TensorFlow inference model (.tflite) for Skystone game elements.
   * Includes sample Skystone TensorFlow OpModes (Java).
   * Includes sample Skystone TensorFlow OpModes (Blocks).
* Removes older (season-specific) sample OpModes.
* Includes 64-bit support (to comply with [Google Play requirements](https://android-developers.googleblog.com/2019/01/get-your-apps-ready-for-64-bit.html)).
* Protects against Stuck OpModes when a Restart Robot is requested. (Thanks to FROGbots-4634) ([ftc_app issue #709](https://github.com/ftctechnh/ftc_app/issues/709))
* Blocks related changes:
   * Fixes bug with blocks generated code when hardware device name is a java or javascript reserved word.
   * Shows generated java code for blocks, even when hardware items are missing from the active configuration.
   * Displays warning icon when outdated Vuforia and TensorFlow blocks are used ([SkyStone issue #27](https://github.com/FIRST-Tech-Challenge/SkyStone/issues/27))

## Version 5.1 (20190820-222104)
* Defines default PIDF parameters for the following motors:
    * REV Core Hex Motor
    * REV 20:1 HD Hex Motor
    * REV 40:1 HD Hex Motor
* Adds back button when running on a device without a system back button (such as a Control Hub)
* Allows a REV Control Hub to update the firmware on a REV Expansion Hub via USB
* Fixes [SkyStone issue #9](https://github.com/FIRST-Tech-Challenge/SkyStone/issues/9)
* Fixes [ftc_app issue #715](https://github.com/ftctechnh/ftc_app/issues/715)
* Prevents extra DS User clicks by filtering based on current state.
* Prevents incorrect DS UI state changes when receiving new OpMode list from RC
* Adds support for REV Color Sensor V3
* Adds a manual-refresh DS Camera Stream for remotely viewing RC camera frames.
    * To show the stream on the DS, initialize **but do not run** a stream-enabled opmode, select the Camera Stream option in the DS menu, and tap the image to refresh. This feature is automatically enabled when using Vuforia or TFOD—no additional RC configuration is required for typical use cases. To hide the stream, select the same menu item again.
    * Note that gamepads are disabled and the selected opmode cannot be started while the stream is open as a safety precaution.
    * To use custom streams, consult the API docs for `CameraStreamServer#setSource` and `CameraStreamSource`.
* Adds many Star Wars sounds to RobotController resources.
* Added Skystone Sounds Chooser Sample Program.
* Switches out startup, connect chimes, and error/warning sounds for Star Wars sounds
* Updates OnBot Java to use a WebSocket for communication with the robot
    * The OnBot Java page no longer has to do a full refresh when a user switches from editing one file to another

Known issues:
* Camera Stream
    * The Vuforia camera stream inherits the issues present in the phone preview (namely [ftc_app issue #574](https://github.com/ftctechnh/ftc_app/issues/574)). This problem does not affect the TFOD camera stream even though it receives frames from Vuforia.
    * The orientation of the stream frames may not always match the phone preview. For now, these frames may be rotated manually via a custom `CameraStreamSource` if desired.
* OnBotJava
    * Browser back button may not always work correctly
    * It's possible for a build to be queued, but not started. The OnBot Java build console will display a warning if this occurs.
    * A user might not realize they are editing a different file if the user inadvertently switches from one file to another since this switch is now seamless. The name of the currently open file is displayed in the browser tab.
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

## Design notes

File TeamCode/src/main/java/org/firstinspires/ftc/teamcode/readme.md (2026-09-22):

## TeamCode Module

This module contains the Phoenix differential-swerve drivetrain, shared safety runtime, encoder diagnostics, guarded Pedro 3.0.1 integration, and commissioning OpModes. It is not an empty starter module.

Use `PedroAutoDrive` for autonomous ownership and the disabled `PedroAutoTemplate` for a complete example. Keep each diagnostic scoped to the hardware it tests. Do not initialize unrelated subsystems or use Pedro's generic `Swerve` for this differential robot. Consult the repository-root `README.md`, `PROJECT_DESIGN.md`, `INTEGRATION_STATUS.md`, and `HUMAN_TASKS.md` before enabling path OpModes.

## Creating your own OpModes

The easiest way to create your own OpMode is to copy a Sample OpMode and make it your own.

Sample opmodes exist in the FtcRobotController module.
To locate these samples, find the FtcRobotController module in the "Project/Android" tab.

Expand the following tree elements:
 FtcRobotController/java/org.firstinspires.ftc.robotcontroller/external/samples

### Naming of Samples

To gain a better understanding of how the samples are organized, and how to interpret the
naming system, it will help to understand the conventions that were used during their creation.

These conventions are described (in detail) in the sample_conventions.md file in this folder.

To summarize: A range of different samples classes will reside in the java/external/samples.
The class names will follow a naming convention which indicates the purpose of each class.
The prefix of the name will be one of the following:

Basic:  	This is a minimally functional OpMode used to illustrate the skeleton/structure
            of a particular style of OpMode.  These are bare bones examples.

Sensor:    	This is a Sample OpMode that shows how to use a specific sensor.
            It is not intended to drive a functioning robot, it is simply showing the minimal code
            required to read and display the sensor values.

Robot:	    This is a Sample OpMode that assumes a simple two-motor (differential) drive base.
            It may be used to provide a common baseline driving OpMode, or
            to demonstrate how a particular sensor or concept can be used to navigate.

Concept:	This is a sample OpMode that illustrates performing a specific function or concept.
            These may be complex, but their operation should be explained clearly in the comments,
            or the comments should reference an external doc, guide or tutorial.
            Each OpMode should try to only demonstrate a single concept so they are easy to
            locate based on their name.  These OpModes may not produce a drivable robot.

After the prefix, other conventions will apply:

* Sensor class names are constructed as:    Sensor - Company - Type
* Robot class names are constructed as:     Robot - Mode - Action - OpModetype
* Concept class names are constructed as:   Concept - Topic - OpModetype

Once you are familiar with the range of samples available, you can choose one to be the
basis for your own robot.  In all cases, the desired sample(s) needs to be copied into
your TeamCode module to be used.

This is done inside Android Studio directly, using the following steps:

 1) Locate the desired sample class in the Project/Android tree.

 2) Right click on the sample class and select "Copy"

 3) Expand the  TeamCode/java folder

 4) Right click on the org.firstinspires.ftc.teamcode folder and select "Paste"

 5) You will be prompted for a class name for the copy.
    Choose something meaningful based on the purpose of this class.
    Start with a capital letter, and remember that there may be more similar classes later.

Once your copy has been created, you should prepare it for use on your robot.
This is done by adjusting the OpMode's name, and enabling it to be displayed on the
Driver Station's OpMode list.

Each OpMode sample class begins with several lines of code like the ones shown below:

```
 @TeleOp(name="Template: Linear OpMode", group="Linear Opmode")
 @Disabled
```

The name that will appear on the driver station's "opmode list" is defined by the code:
 ``name="Template: Linear OpMode"``
You can change what appears between the quotes to better describe your opmode.
The "group=" portion of the code can be used to help organize your list of OpModes.

As shown, the current OpMode will NOT appear on the driver station's OpMode list because of the
  ``@Disabled`` annotation which has been included.
This line can simply be deleted , or commented out, to make the OpMode visible.

## ADVANCED Multi-Team App management:  Cloning the TeamCode Module

In some situations, you have multiple teams in your club and you want them to all share
a common code organization, with each being able to *see* the others code but each having
their own team module with their own code that they maintain themselves.

In this situation, you might wish to clone the TeamCode module, once for each of these teams.
Each of the clones would then appear along side each other in the Android Studio module list,
together with the FtcRobotController module (and the original TeamCode module).

Selective Team phones can then be programmed by selecting the desired Module from the pulldown list
prior to clicking to the green Run arrow.

Warning:  This is not for the inexperienced Software developer.
You will need to be comfortable with File manipulations and managing Android Studio Modules.
These changes are performed OUTSIDE of Android Studios, so close Android Studios before you do this.
 
Also.. Make a full project backup before you start this :)

To clone TeamCode, do the following:

Note: Some names start with "Team" and others start with "team".  This is intentional.

1)  Using your operating system file management tools, copy the whole "TeamCode"
    folder to a sibling folder with a corresponding new name, eg: "Team0417".

2)  In the new Team0417 folder, delete the TeamCode.iml file.

3)  the new Team0417 folder, rename the "src/main/java/org/firstinspires/ftc/teamcode" folder
    to a matching name with a lowercase 'team' eg:  "team0417".

4)  In the new Team0417/src/main folder, edit the "AndroidManifest.xml" file, change the line that contains
         package="org.firstinspires.ftc.teamcode"
    to be
         package="org.firstinspires.ftc.team0417"

5)  Add:    include ':Team0417' to the "/settings.gradle" file.
    
6)  Open up Android Studios and clean out any old files by using the menu to "Build/Clean Project""

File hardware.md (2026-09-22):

# Drivetrain Hardware

This document describes the current [Differential Swerve TeleOp](TeamCode/src/main/java/org/firstinspires/ftc/teamcode/DifferentialSwerveTeleOp.java), [combined pod encoder diagnostic](TeamCode/src/main/java/org/firstinspires/ftc/teamcode/SwervePodEncoderTest.java), [analog encoder display](TeamCode/src/main/java/org/firstinspires/ftc/teamcode/PodAnalogEncoderTest.java), and [individual motor drive diagnostic](TeamCode/src/main/java/org/firstinspires/ftc/teamcode/MotorEncoderDriveTest.java). See [README.md](README.md) for the operating overview, [PROJECT_DESIGN.md](PROJECT_DESIGN.md) for architecture and coding requirements, and [HUMAN_TASKS.md](HUMAN_TASKS.md) for the complete human-run calibration checklist.

## Current Scope

The drive is **robot-centric**, using four motors on the Control Hub and two Melonbotics pod-azimuth encoders with analog outputs on the Control Hub and quadrature outputs on the Expansion Hub. Neither OpMode requires Pinpoint or odometry. The drive has no chassis heading sensor, field reference, or active chassis heading hold.

Earlier Pinpoint mounting and field-centric setup notes describe a superseded configuration and are not prerequisites for these OpModes. SDK samples and SDK support for that hardware are independent of the team's drive implementation.

## Control Hub Motors

| Motor/Encoder Port | Configuration Name | Position |
| --- | --- | --- |
| 0 | `motor0` | Left pod, left motor |
| 1 | `motor1` | Left pod, right motor |
| 2 | `motor2` | Right pod, left motor |
| 3 | `motor3` | Right pod, right motor |

- Four goBILDA 5203-2402-0005 Yellow Jacket motors with 5.2:1 planetary gearboxes.
- Rated no-load output speed: **1150 RPM at 12 V**.
- Built-in encoder resolution: **28 pulses per encoder-shaft revolution** and **145.1 pulses per gearbox-output revolution**; 28 at the encoder shaft is not the output-shaft value.
- Each motor encoder connects to the encoder port matching its motor port on the Control Hub.
- All four motors are wired red-to-red/black-to-black and use software direction `FORWARD`.
- Confirmed individual motor behavior with the robot raised, using `Individual Motor Drive Test` and joystick-up/positive command: `motor0` and `motor2` rotate their pods counterclockwise; `motor1` and `motor3` rotate their pods clockwise, viewed from above. Joystick-down reverses each response. All four software directions remain `FORWARD`.
- Initial combined testing showed positive differential steering turned both pods left/counterclockwise. The selected-pod diagnostic converts right-stick-right to negative differential steering; startup and runtime closed-loop steering use the same conversion. Main-drive right-stick X commands chassis rotation and stays clockwise-positive. With both pods facing forward according to their analog-zero references, equal positive wheel commands propel the robot forward; this was confirmed during powered testing.
- The four built-in encoders provide motor-velocity and raw count feedback. The active drive OpMode does not use their positions to estimate pod azimuth and does not reset their counts. `Individual Motor Drive Test` powers one selected motor at a time, capped at 25%, or drives one selected pod with the real differential mix at a capped 420 ticks/s. Hold LB for the left pod or RB for the right pod; left stick is drive and right stick X is steering. Use it with the robot raised.

The motors run in `RUN_USING_ENCODER` with velocity PIDF and `BRAKE` zero-power behavior. The physical hardware configuration, separate quadrature hub, and documented differential assembly have been verified. `setVelocity()` and motor velocity telemetry use ticks/second. The calculated no-load maximum is `1150 * 145.1 / 60 = 2781.08 ticks/s`.

Each motor's velocity contains both wheel-drive and steering components. Equal motor velocities produce wheel drive; their difference produces steering. Motor feedback is therefore not an independent wheel-only sensor.

## Melonbotics Pod Encoders

Each Melonbotics Through Bore Encoder supplies quadrature on its 4-pin JST and absolute analog position on its 3-pin JST. Encoder shaft to pod-azimuth gearing is **1:1**. Clockwise means looking down from above the robot.

### Expansion Hub Quadrature

| Encoder Port | Configuration Name | Measurement | Current Software Sign |
| --- | --- | --- | --- |
| 0 | `encoderleft` | Left pod azimuth | +1, confirmed clockwise-positive |
| 1 | `encoderright` | Right pod azimuth | +1, confirmed clockwise-positive |

These connections are unchanged. Melonbotics specifies **1024 CPR quadrature output resolution** on the 4-pin JST. The encoder body also provides absolute analog output on the 3-pin JST. Both outputs measure the same shaft, and the encoder shaft is mechanically **1:1 with pod azimuth**. The measured result is approximately 4100 raw counts per pod revolution on both pods. This is close enough to the configured `COUNTS_PER_REVOLUTION = 4096.0` and is mechanically consistent with the Melonbotics 1024 CPR encoder using 4x quadrature decoding. A 90-degree measurement helps check scale and direction, but is not a substitute for a full revolution.

Rolling the drive wheel without rotating the pod should not change these counts.

In Robot Configuration, assign `encoderleft` and `encoderright` to Expansion Hub **motor channels 0 and 1**. The SDK exposes quadrature encoder inputs through those channels even with no motors attached. These channel handles are read-only for quadrature measurement: no output or hardware-reset command is sent to them. The encoder diagnostic’s explicit Y alignment action commands only the selected drive pod’s motors; it never commands the quadrature channel handles.

Both OpModes read raw controller counts, bypassing motor-channel direction adjustments. Their normal measurement paths are read-only; the documented alignment hotkeys are the only motor-command exception. The drive checks that the encoders share a controller on ports 0/1 and are on a different controller from the drive motors. Confirm the actual hub assignment in Robot Configuration; names alone do not establish physical wiring.

### Control Hub Analog

| Analog Channel | Configuration Name | Measurement |
| --- | --- | --- |
| 0 | `absencleft` | Left pod absolute azimuth |
| 1 | `absencright` | Right pod absolute azimuth |

Use **ONE joiner cable into the Control Hub's physical analog connector labeled 0-1**. The joiner routes two independent encoder signals to channels 0 and 1; it does not merge them into a single input. Configure **two AnalogInput hardware names** as above. Confirm the actual assignment by moving one pod at a time and checking connection telemetry; names alone do not prove wiring. Follow the manufacturer's joiner wiring and REV port pinout rather than tying the two signal wires together.

Melonbotics specifies a **0..3.2 V output at 3.3 V supply**, 12-bit DAC, maximum integral non-linearity of +/-1 degree, and 5 us propagation delay. The code uses `rawDegrees = min(volts, 3.2) / 3.2 * 360`, not the hub's maximum input voltage. Validation accepts finite 0..3.3 V readings; the upper 0.1 V margin is clamped to the wrap endpoint to avoid rejecting slightly overscale measurements. Invalid feedback reports the measured voltage. **0 V can be a valid angle or a disconnected sensor**; this check is not reliable disconnect protection.

### Forward References and Startup

Calibration and tracking are shared by the drive and encoder diagnostics through [SwervePodEncoder.java](TeamCode/src/main/java/org/firstinspires/ftc/teamcode/SwervePodEncoder.java). The complete physical discovery procedure is recorded in [HUMAN_TASKS.md](HUMAN_TASKS.md). `LEFT_FORWARD_DEGREES` and `RIGHT_FORWARD_DEGREES` are independent raw analog references for the **directed wheel-travel axis facing robot-forward**, not merely a wheel plane that could point forward or backward. The measured top-dead-center zero references are left **0.122 V = 13.725°** and right **0.258 V = 29.025°**. `CALIBRATION_VERIFIED` is now `true` because hardware configuration, encoder signs/scale, individual motor responses, and combined pod steering direction have been verified. The drive still performs bounded startup alignment and refuses to continue if alignment or feedback fails.

The right module is rotated 180 degrees, **not mirrored**. Its independent forward reference absorbs that mounting rotation: do not add another 180 degrees or negate right feedback just because it is rotated. The analog signs are confirmed as `-1` for both pods because both raw voltages decrease during clockwise rotation. Both quadrature signs are confirmed as `+1` because clockwise rotation increased both raw counts. The accepted software scale is 4096 counts per revolution; both pods measured approximately 4100 counts, consistent with the 1024 CPR / 4x quadrature specification. Both pods remain centered at the existing left/right positions, so the kinematics and motor mixing are unchanged. Combined pod steering direction and forward wheel-drive direction have been confirmed; loaded behavior remains a commissioning task.

Once calibrated, the drive obtains fresh hub snapshots **during INIT** and automatically steers both pods to their independent analog forward references. Alignment uses proportional steering capped at 0.20 command, with a 0.03 minimum command outside the 2° settling window to overcome static friction near the target. It requires 100 ms continuously inside the 2° target window and times out after 5 seconds. Either pod failing stops both. READY indicates completion; motors wait at zero velocity until Start. An early Start waits for alignment to finish. At Start, a fresh validated snapshot supplies quadrature baselines and residual analog angles. Both pods must still be within tolerance; if moved while waiting, reinitialize. **Pods move on INIT; keep clear before pressing INIT.**

```text
initial angle = wrap((raw analog degrees - pod forward degrees) * analog sign)
delta angle (radians) = delta encoder counts * quadrature sign * 2 * PI / COUNTS_PER_REVOLUTION
```

After seeding, the drive uses **quadrature only**, with no runtime analog correction or reseeding. Counter differences are computed as integers to handle signed rollover, and accumulated azimuth is wrapped. Pod angular rate is calculated from those differences and elapsed loop time. The motor-encoder gearing calculation from earlier versions is no longer used for steering feedback.

### Mechanical Analog Centering

Mechanically index each encoder so directed robot-forward is near **1.6 V = 180 raw degrees** where practical. This gives a +/-100-degree operating excursion about forward with about 80 degrees remaining to the DAC wrap on either side, or a +/-80-degree excursion with about 100 degrees remaining. Measure each actual forward reference rather than assuming exactly 180 degrees, even if both encoders are centered.

A software forward offset changes reported robot-relative zero; it **cannot move the hardware voltage wrap**. The 3.2-to-0 V transition is an angular wrap, not a dead zone or hard steering limit. These margins describe distance to that transition, not enforced travel constraints. Shortest-path steering bounds target error, not physical azimuth or overshoot.

### Sources

- [Melonbotics Through Bore Encoder specifications](https://docs.melonbotics.com/through-bore-encoder.md): 7 mm hex bore compatible with 8 mm REX, 1024 CPR quadrature output, and analog output.
- [Melonbotics analog output guide](https://docs.melonbotics.com/through-bore-encoder/how-to-use-analog-output.md): 0..3.2 V range, analog specifications, and two-encoder joiner wiring.
- [REV Control/Expansion Hub port pinouts](https://docs.revrobotics.com/duo-control/control-system-overview/port-pinouts.md): physical connector/channel wiring.

## Mechanical Geometry and Programmed Ratio

| Parameter | Confirmed Value |
| --- | --- |
| Wheel diameter | 63.25 mm |
| Pod wheel-center spacing | 359.5 mm |
| Pod locations | Directly left/right of robot center |
| Initial bevel pair, each motor | 1:1 |
| Spur stage | 16-tooth driving 54-tooth |
| Wheel bevel stage | 50-tooth driving 19-tooth |
| Wheel-drive ratio | `(16/54) * (50/19) = 0.779727` |

Each motor drives a horizontal-to-vertical 1:1 bevel pair followed by its own 16:54 stage. The right motor feeds the upper differential part; the left motor feeds the lower part. The upper and lower 54-tooth gears are rigidly attached to their respective 50-tooth bevel gears, and both 50-tooth gears engage the common 19-tooth wheel gear. Equal motor motion is the wheel-drive component; motor motion in opposite directions is the pod-steering component. This is the known differential topology used by the motor-mixing code.

The complete programmed external ratio is `(16/54) * (50/19) = 0.779727` wheel revolutions per motor-output revolution. With the 1150 RPM motor rating and 63.25 mm wheel, the theoretical no-load wheel speed is approximately **2.970 m/s**. This is used to convert chassis rotation requests into normalized pod speeds; it is not a measured loaded operating limit.

## Controls and Motor Mixing

- Left-stick direction selects robot-relative travel direction; distance from center selects speed after radial deadband rescaling.
- Right-stick X commands rotation about the pod midpoint: right is clockwise, left is counterclockwise. Rotation input is cubed after its deadband.
- Full-stick pure rotation uses the full wheel-speed range of both pods. When aligned forward, all four hardware motors request approximately +2781 ticks/s for a right turn; a left turn reverses all four signs. Logical wheel speeds are opposite: left forward/right reverse for clockwise motion, followed by the right pod negate-and-swap hardware mapping. Misalignment reduces drive to preserve steering authority.
- Releasing right-stick X commands zero chassis rotation, with no heading hold or return-to-forward behavior.
- Triggers are unused.
- At zero requested pod velocity, its previous azimuth target is retained. A wholly zero chassis command sets all four motor velocities to zero with BRAKE; a zero-speed pod within a nonzero chassis request may still steer toward its retained target.

Per pod, the controller optimizes the requested vector by reversing wheel direction when appropriate. A 3° hysteresis band around the 90° reversal boundary prevents chatter, allowing up to 93° retained steering error. It applies PD steering with measured-rate damping, a steering-command slew limit, and cosine-squared alignment scaling; wheel drive is zero at or beyond 90° error.

```text
left motor velocity  = wheel-drive component + steering component
right motor velocity = wheel-drive component - steering component
```

Positive steering in this motor mix is **counterclockwise** on both measured pods. The clockwise-positive PD correction is converted at the motor boundary: `steering component = -(STEERING_KP * error - STEERING_KD * measuredRate)`. Startup alignment and runtime steering share this conversion. The previous runtime implementation omitted it, creating positive feedback as soon as motion introduced an angle error. Main-drive chassis rotation must not be inverted to compensate for this pod-level polarity.

Steering has priority within the motor-speed limit; drive uses the remaining headroom. This avoids independently clipping the motor commands and changing the requested steering component. Driving and steering cannot simultaneously demand each motor's full capacity.

## Preliminary Tuning

These are current source defaults, **not validated gains or safe operating limits**:

| Setting | Value | Meaning |
| --- | --- | --- |
| Pod `DEFAULT_KP` | 0.5 | Normalized steering output per radian of error |
| Pod `DEFAULT_KD` | 0.01 | Measured-rate damping, normalized output per rad/s |
| `PedroDriveConfig.TELEOP_MAX_DRIVE` | 1.0 | Wheel-drive command scale |
| Pod `DEFAULT_MAX_STEER` | 0.20 | Steering component limit, matching startup cap |
| `DRIVE_DEADBAND`, `TURN_DEADBAND` | 0.05 | Stick deadbands |
| Input `MAX_TURN_RATE` | `2 * MAX_WHEEL_SPEED_METERS_PER_SECOND / TRACK_WIDTH_METERS`, about 16.52 rad/s | Theoretical full-stick pure rotation scale: opposite wheels at full speed, not a measured loaded chassis rate |
| Pod `DEFAULT_SLEW_RATE` | 2.0/s | Normalized steering-command change limit; nonpositive disables it |
| `SwerveTuning.MOTOR_VELOCITY_P/I/D` | 15.0, 0.5, 0.5 | REV motor velocity controller gains |
| `SwerveTuning.MOTOR_VELOCITY_F` | `32767 / 2781.0833`, about 11.782 | Preliminary REV velocity feedforward, not volts/RPM |

`SwerveTuning` owns live motor PIDF, steering PD/slew/cap, and alignment tuning. `SwerveDriverInput` owns input shaping; `PedroDriveConfig` owns drive profiles. The runtime reapplies changed PIDF values, and the pods validate output limits on every preparation. Record tuned values back into source before redeploying; Dashboard changes are session-only.

## Commissioning and Faults

1. Run the **Pod Analog Encoder Test**. LB selects the left pod, RB selects the right pod, A steers the selected pod toward its configured forward analog reference, and B aborts. If a reference has not yet been entered, the test targets analog 0 degrees. Keep the robot raised and clear during alignment.
2. Run the **Individual Motor Drive Test** with the robot raised. D-pad selects `motor0`–`motor3` for individual direction checks. Hold LB to drive the left pod or RB to drive the right pod with the actual `drive + steer` / `drive - steer` differential mix; left stick is drive, right stick X is steering, and combined output is capped at 420 ticks/s.
3. Run the **Swerve Pod Encoder Test**. LB/RB select a pod, A zeroes the selected quadrature display in software, X starts/finishes a manual 360-degree measurement, Y steers the selected pod to its analog forward reference, and B aborts alignment.
4. Verify the accepted 4096-count scale and positive clockwise sign. Wheel rotation has been confirmed not to change pod quadrature counts.
5. The analog zero references are recorded as left 0.122 V / 13.725° and right 0.258 V / 29.025°. Encoder scale/sign, analog polarity, channel assignment, and combined pod steering direction are confirmed; `CALIBRATION_VERIFIED` is enabled. Continue with powered drive commissioning.
6. Run the main drive with wheels raised and reduced limits. INIT aligns and settles both pods. Wait for READY, then press Start to capture fresh quadrature baselines and drive. Alignment timeout or invalid feedback stops both pods.
8. Test forward/reverse, strafing, clockwise/counterclockwise turning, combined motion, and turn-stick release at low speed. Test pod-angle wraparound, shortest-path reversals near 90 degrees, and Stop behavior. Tune velocity control, steering PD, slew, and driver feel before increasing limits.

The drive reads one validated bulk snapshot per configured hub per normal loop and updates telemetry at 10 Hz. An invalid read commands zero velocity before retrying the entire hub set: up to three total attempts within 150 ms, 10 ms apart. During driving, recovered reads require neutral sticks and analog/quadrature agreement within 10° before resuming; trackers are not reseeded. Recovery time counts toward the 250 ms loop limit. Persistent failures latch a stopped telemetry state until Stop/reinitialization. Fault telemetry/logs include the configured hub name, connection, parent/downstream role, and failure reason; a module address alone does not identify Control versus Expansion Hub. Shutdown attempts every motor stop and restores prior hub caching modes. The encoder diagnostic also temporarily uses manual caching and restores prior modes at Stop.

Software checks cannot interrupt a blocked SDK call or guarantee delivery of a failed stop command. A disconnected or frozen quadrature encoder can still return valid hub data and is not reliably detected. A disconnected analog input can read a valid 0 V and seed an incorrect angle; there is no reliable disconnect protection, and analog is not used for runtime correction. Because every configured hub is checked, an unrelated hub fault can also stop the drive or suppress a diagnostic reading.

The debug APK build and unit tests passed with `./gradlew.bat :TeamCode:testDebugUnitTest :TeamCode:assembleDebug`. Tests cover encoder math, steering/damping polarity, chassis kinematics, limits, and simulated closed-loop convergence. They do not exercise real hub wiring or powered OpMode behavior. Complete [HUMAN_TASKS.md](HUMAN_TASKS.md) for powered commissioning, tuning, and final acceptance. PIDF/PD tuning, loaded speed, stopping behavior, actual Control Hub loop timing, and Pinpoint frame verification remain to be completed on the robot.

## Pedro / Pinpoint integration settings

The application consumes `com.pedropathing:revhub:3.0.1`. The robot frame is X forward, Y left,
and CCW-positive yaw. Drive-pod centers are `(0, +7.0767716535 in)` left and
`(0, -7.0767716535 in)` right. The Pinpoint odometry offsets are independent: X pod
`+199.25 mm` (left of center) and Y pod `+88.0 mm` (forward of center), using two
`goBILDA_4_BAR_POD` presets and global inches.

Current commissioned direction settings are X `FORWARD`, Y `FORWARD`, with a
`COUNTERCLOCKWISE_POSITIVE` heading convention. `PinpointSettings` accepts these values for powered
Pedro arming. Continue monitoring the following during commissioning:

| Observation | Expected | Recorded result |
| --- | --- | --- |
| Forward translation | field X increases | PASS |
| Left translation | field Y increases | PASS |
| CCW rotation | heading and angular rate increase | PASS |
| Forward at +90 degrees | field Y increases | PASS |
| 24 in forward scale | within 2% | PASS |
| 24 in left scale | within 2% | PASS |
| Rotation-in-place translation drift | at most 1 in initially | PASS |

Autonomous commissioning uses a `0.15` wheel-drive component and `0.20` normalized turn envelope.
The existing `0.20` steering component is retained, for a configured combined commissioning cap of
`0.35`. Motor targets remain: left pod `(logicalLeft, logicalRight)` and right pod
`(-logicalRight, -logicalLeft)`, multiplied once by `2781.083333 ticks/s`. Zero commands and all
faults retain `RUN_USING_ENCODER` plus BRAKE; voltage compensation and X-lock are disabled.

The 0.35 autonomous combined cap is enforced at each motor preparation, including after Dashboard edits; increasing steering above the available commissioning headroom stops the run. Normal TeleOp uses a separate 1.0 motor envelope. Hardware loop timing, actual stop delivery, and loaded dynamics remain subject to physical testing. See [INTEGRATION_STATUS.md](INTEGRATION_STATUS.md) for the September 21 software verification results.

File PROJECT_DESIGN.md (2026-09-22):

# Project Design

## Purpose

This project controls and commissions a two-pod differential-swerve FTC drivetrain. This document records the design decisions that explain why the code is structured and behaves as it does. Hardware specifications and wiring details are maintained in [hardware.md](hardware.md); the human-run calibration and commissioning procedure is maintained in [HUMAN_TASKS.md](HUMAN_TASKS.md). This document focuses on system architecture, software behavior, and coding requirements.

## Design Requirements

1. The robot shall use two differential-swerve pods, with two motors per pod.
2. The drive shall support robot-centric translation and chassis rotation.
3. Pod azimuth shall use the dedicated Melonbotics encoder quadrature outputs for runtime tracking.
4. Absolute analog encoder outputs shall provide the startup azimuth reference.
5. During INIT, the main drive shall steer both pods to their independent analog forward references; driver motion starts only after both alignment and Start.
6. The drive shall remain disabled until encoder calibration has been physically measured and verified.
7. Diagnostics shall be read-only whenever they are intended for wiring or calibration work; motor-assisted alignment actions must be explicit, bounded, and abortable.
8. Invalid hub feedback shall stop motor commands before bounded retries. Persistent feedback faults shall latch stopped until OpMode restart; recovered runtime feedback requires neutral sticks and consistent pod angles before resuming.
9. **Each independent robot subsystem or diagnostic function shall be implemented in its own OpMode file.** Do not combine unrelated subsystem tests into one large OpMode. Shared calculations and constants belong in reusable classes. An OpMode may delegate hardware ownership and lifecycle to a subsystem-scoped owner, provided acquisition/cleanup remain within that OpMode lifetime and unrelated hardware is not initialized.

## Architecture

### OpModes

- `DifferentialSwerveTeleOp` owns gamepad interpretation and telemetry and scopes a `DifferentialSwerveRuntime` for hardware acquisition, alignment, feedback, and output cleanup.
- `SwervePodEncoderTest` owns the combined analog/quadrature encoder commissioning workflow; its normal measurement path is read-only and its Y action is bounded selected-pod alignment.
- `PodAnalogEncoderTest` owns analog display and bounded selected-pod alignment to the forward reference.
- `MotorEncoderDriveTest` owns the bounded individual-motor direction and module-response workflow.

New robot subsystems should follow the same separation. Examples include an intake test, lift test, vision test, or autonomous subsystem test: each should have a separate appropriately named OpMode rather than being added to the drivetrain OpMode.

### Shared class

`SwervePodEncoder` contains hardware-independent encoder math and calibration constants shared by the drive and encoder diagnostics. `PodAlignmentController` contains the shared bounded analog-feedback alignment state machine. Neither class acquires hardware, sends motor commands, or owns an OpMode lifecycle.

`DifferentialSwerveKinematics` converts robot-relative translation and clockwise-positive chassis rotation to pod vectors. `DifferentialSwervePodController` owns shortest-path optimization, PD steering, slew state, alignment scaling, and normalized motor mixing. Its clockwise-to-motor-steering conversion is shared with startup alignment and the individual pod diagnostic.

`SwerveDriverInput` owns radial translation deadband and cubic rotation shaping. The shared runtime handles initialization, alignment, analog-to-quadrature handoff, and cycle authorization through a small injectable `Host` boundary. `DifferentialSwerveHardware` implements that boundary with the SDK; `SwerveHubSession` coordinates snapshots and restores cache modes. Encoder state stays in the trackers. `SwerveTuning` provides validated live Dashboard settings; changed motor PIDF values are reapplied during runtime.

This separation keeps the math and alignment safety rules unit-testable and prevents the drive and diagnostics from developing different timeout, clamp, or wrap behavior.

## Hardware and Naming Decisions

### Drive motors

Four goBILDA `5203-2402-0005` motors are assigned to the Control Hub:

| Name | Port | Position |
|---|---:|---|
| `motor0` | 0 | Left pod, left motor |
| `motor1` | 1 | Left pod, right motor |
| `motor2` | 2 | Right pod, left motor |
| `motor3` | 3 | Right pod, right motor |

The motor specification used by the software is:

- 1150 RPM no-load output speed at 12 V
- 5.2:1 planetary gearbox
- 28 pulses per encoder-shaft revolution
- 145.1 pulses per gearbox-output revolution

The code uses the 145.1 gearbox-output value for velocity control because motor commands and telemetry are expressed at the gearbox output. Motor encoder positions are not used as the active pod-angle sensor.

### Pod encoders

Each Melonbotics Through Bore Encoder contains both sensing outputs and is mechanically 1:1 with pod azimuth:

- Quadrature: Expansion Hub motor channels 0 and 1, named `encoderleft` and `encoderright`
- Analog: Control Hub analog channels 0 and 1, named `absencleft` and `absencright`
- Encoder specification: 1024 CPR; software pod tracking scale: 4096 raw counts/revolution
- Analog range: 0–3.2 V

Raw controller counts are read directly so motor-channel direction settings cannot silently change encoder polarity.

## Mechanical Ratio

The programmed wheel-drive ratio is:

```text
(16 / 54) * (50 / 19) = 0.779727
```

The known differential setup is:

1. Each motor has an initial horizontal-to-vertical bevel pair with a 1:1 ratio.
2. Each motor then drives its own 16-tooth gear into a 54-tooth gear.
3. Each 54-tooth gear is rigidly attached to a 50-tooth gear.
4. The two 50-tooth gears engage the common 19-tooth wheel gear.
5. The left motor feeds the lower differential path and the right motor feeds the upper differential path.

Equal motor motion produces the wheel-drive component. The difference between the motor motions produces the pod-steering component. The ratio is used to estimate wheel speed and convert chassis rotation requests into normalized pod speeds. The estimate is theoretical; loaded speed, slip, and actual mechanical efficiency must be measured on the robot.

## Differential Motor Mixing

Each pod uses the same differential convention:

```text
left motor velocity  = wheel-drive component + steering component
right motor velocity = wheel-drive component - steering component
```

Equal motor velocities produce wheel drive. Opposite motor velocities produce pod steering. The right pod is physically rotated 180 degrees but is not treated as mirrored in software; its independent analog forward reference accounts for the mounting orientation.

The confirmed motor response is **counterclockwise** for positive steering in this mix. Encoder angles, errors, and measured rates are **clockwise-positive**, so `steering component = -(Kp * error - Kd * measuredRate)`. Both PD terms must be converted together. Applying this polarity only during analog alignment leaves the runtime loop in positive feedback. Chassis rotation remains clockwise-positive: right-stick right requests left-wheel forward/right-wheel backward, independently of the pod-steering polarity.

The controller reverses wheel direction to use the equivalent shorter steering path. Its first choice uses the 90° boundary; subsequent choices use a 3° hysteresis band (switch to reverse above 93°, back below 87°). This avoids chatter near perpendicular and permits up to 93° retained steering error. Wheel drive is suppressed whenever absolute error is at least 90°. Individual motor signs cannot be assumed fixed for every driver command.

## Encoder Calibration and Tracking

During INIT, the drive:

1. Reads both analog voltages.
2. Converts them to raw degrees with `volts / 3.2 * 360`.
3. Computes each signed shortest error to its independently measured forward reference.
4. Uses proportional velocity capped at 0.20 command, requiring 100 ms continuously within the 2° target window before the 5-second timeout, with correction polarity matched to the measured directions.
5. Stops both pods immediately if either fails. Completed pods are checked for drift while their partner finishes. The same 250 ms delay limit used in driving also applies during alignment.
6. Reports READY and waits at zero velocity for Start. The bounded alignment loop uses Stop as its cancellation condition, so it runs during INIT and finishes if Start is pressed early.
7. At Start, takes a fresh validated snapshot, verifies both pods are still within tolerance, and seeds quadrature with the measured residual analog angles and raw counts. The first runtime interval starts at that snapshot, not before the INIT wait. A pod moved out of tolerance requires reinitialization.

Analog validation accepts finite 0..3.3 V readings, allowing a margin above the nominal 3.2 V DAC endpoint. Conversion clamps that upper margin to 360° while retaining the 3.2 V scale and measured forward references. Invalid readings report the voltage; they are not silently replaced with zero.

After startup, runtime angle tracking uses quadrature only:

```text
delta angle = delta counts * quadrature sign * 2π / 4096
```

Analog is not repeatedly used for correction because the analog output wraps at the voltage boundary and can introduce discontinuities during normal steering. Quadrature count differences are calculated as integers before conversion so signed rollover is handled correctly.

The measured top-dead-center forward references are stored independently: left 0.122 V / 13.725° and right 0.258 V / 29.025°. Both analog voltages decrease during clockwise rotation, so both analog signs are `-1`. Both quadrature signs are confirmed as `+1` because clockwise rotation increased both raw counts. Wheel-drive direction and low-speed motion were previously confirmed; the refactored lifecycle requires a physical regression, and loaded behavior remains unverified. `CALIBRATION_VERIFIED` is true after physical encoder and combined-steering verification; powered drive now proceeds to bounded startup alignment. Powered commissioning and tuning remain separate human tasks.

## Control Decisions

- **Robot-centric TeleOp:** avoids requiring an IMU or field heading reference; Pedro autonomous uses Pinpoint.
- **Left stick translation:** direction selects the requested robot-relative pod vector; radial deadband prevents small joystick noise.
- **Right stick X rotation:** requests clockwise-positive chassis rotation about the pod midpoint; cubic shaping provides finer low-input control.
- **Full-speed pure rotation:** full stick maps to `2 * maxWheelSpeed / trackWidth`, so aligned pods request equal and opposite full wheel speeds using all four motors. Combined motion retains vector normalization and steering headroom. This calculated angular rate is a command scale, not a measured chassis speed.
- **No TeleOp heading hold:** releasing the turn stick requests zero chassis rotation rather than an automatic return or heading correction.
- **Steering priority:** steering commands retain authority when drive and steering compete for the motor-speed limit. Remaining headroom is allocated to wheel drive.
- **Cosine-squared alignment scaling:** wheel drive is reduced while a pod is misaligned with its requested vector.
- **Steering slew limiting:** limits abrupt changes in the steering command.
- **Measured-rate damping:** derivative steering feedback uses measured pod angular rate, avoiding target-step derivative spikes.
- **Bounded runtime steering:** preliminary defaults are Kp 0.5, Kd 0.01, steering limit 0.20, and slew rate 2.0/s. The runtime cap matches startup alignment; actual loaded tuning requires robot verification.

## Safety and Fault Handling

- Encoder measurement diagnostics do not reset hardware encoder counts; the individual motor diagnostic intentionally applies bounded power to one selected motor at a time.
- The drive starts at zero velocity, aligns the pods during INIT, then waits at zero velocity for Start.
- The drive refuses to start without verified calibration.
- Invalid analog values, invalid hub bulk reads, or excessive loop delays stop the drive.
- A failed bulk read commands zero velocity before retrying the entire hub set. `HubSnapshotReader` allows three attempts within 150 ms, with 10 ms pauses. No fake or mixed-attempt data reaches the controllers. The existing 250 ms loop limit still includes recovery time.
- Recovered runtime reads reset steering output state. TeleOp requires neutral sticks before resuming; autonomous latches stopped. Analog/quadrature disagreement above 10° latches a feedback fault, helping catch count resets after hub recovery; this check does not reseed or correct the tracker and cannot detect every reset.
- Persistent feedback faults stay in a stopped telemetry state until Stop/reinitialization. Hub identity and failure details are logged; cleanup attempts every motor stop and cache restoration even if another fails.
- Shutdown attempts to stop every drive motor, even if one stop operation throws.
- Hardware names and ports are checked at runtime, including the requirement that pod quadrature inputs are on Expansion Hub channels 0 and 1 and are on a different hub from the drive motors.
- Software validity checks cannot guarantee that a disconnected analog sensor or frozen quadrature sensor is detected; physical commissioning remains required.

## Diagnostics Design

The diagnostics are intentionally split by purpose:

- Use `PodAnalogEncoderTest` to inspect analog voltage and absolute raw position; LB/RB select a pod, A performs bounded motor-assisted alignment to its forward reference, and B aborts.
- Use `MotorEncoderDriveTest` to power one selected motor at a time at a bounded 25% maximum. D-pad selection and telemetry make individual motor direction and module response visible during physical commissioning.
- Use `SwervePodEncoderTest` to zero a selected quadrature display in software, measure a manual full revolution, compare analog against quadrature, or perform bounded alignment to the selected pod’s analog forward reference.

Calibration captures are session-only. They are reported back and then entered into the shared source constants after review rather than being silently persisted or automatically copied into the drive.

## Code Cleanliness Requirement

Every new feature must first be assigned to a subsystem. The implementation must then follow these rules:

- One subsystem or diagnostic purpose per OpMode file.
- No unrelated motor, sensor, or mechanism tests inside `DifferentialSwerveTeleOp`.
- Shared pure math belongs in a focused helper class with unit tests.
- Hardware lookup and actuator ownership remain scoped to the owning subsystem OpMode, including its shared runtime/hardware owner.
- OpModes must have clear names and FTC groups so the Driver Station menu remains understandable.
- Read-only diagnostics must not call actuator output, direction, mode, target-position, or reset APIs unless that operation is explicitly part of the diagnostic and documented. The alignment hotkeys are the documented exception and are bounded to a selected pod with an abort key and timeout.
- Changes that combine multiple subsystems into one file require a documented safety or lifecycle reason.

This requirement is part of the project design, not merely a style preference: separating subsystem ownership limits accidental hardware interaction, makes tests safer, and keeps commissioning tools usable without running the powered drivetrain.

## Verification Strategy

- Unit-test hardware-independent encoder math, wrapping, calibration validation, signs, and rollover.
- Regression-test startup/runtime polarity agreement, physical damping direction, chassis rotation, shortest-path reversal, target retention, motor limits, and convergence with a simple motor/encoder model.
- Build the TeamCode debug APK after adding or changing an OpMode.
- Complete and record the human-run steps in [HUMAN_TASKS.md](HUMAN_TASKS.md).
- Hardware configuration, separate quadrature hub, differential gear assembly, analog polarity, quadrature polarity, and individual motor responses are physically verified. Combined mixing and low-speed motion were previously reported working. Repeat startup/drive/fault checks after the runtime refactor; loaded dynamics remain unverified.
- Keep powered tests at reduced limits with the robot raised and clear of moving mechanisms.
- Update this document and `hardware.md` whenever a design assumption changes.

## Pedro 3.0.1 integration architecture

Autonomous code owns one `PedroAutoDrive` for the OpMode lifetime. That owner composes a
`SafePedroFollower`, `GuardedPinpointLocalizer`, `DifferentialSwerveDrivetrain`, and the
subsystem-scoped `DifferentialSwerveRuntime`. This is the documented exception to keeping hardware
lookup directly in an OpMode: the runtime owns only drivetrain devices and exists to make hub
snapshot, alignment, authorization, and cleanup behavior identical in TeleOp and autonomous.
OpModes still own construction, user interaction, Start/Stop, and `try/finally` lifetime.

The control sequence is one validated Lynx snapshot, one guarded Pinpoint update, one Pedro
calculation, then a two-pod prepare/validate/commit. Nonzero pod output is rejected without a fresh
runtime authorization. A runtime hub recovery pauses TeleOp until neutral but permanently cancels
autonomous. Stop, localization errors, stale samples, nonfinite commands, and partial output failures
all attempt zero velocity on every drive motor and retain BRAKE.

The shared coordinate contract is X forward, Y left, and positive yaw counterclockwise. Pinpoint
reports field-frame X/Y in inches. Pedro strafe is negated exactly once at the existing
forward/right kinematics boundary; Pedro normalized CCW turn is converted exactly once to the
existing CW rad/s convention. Pod encoder feedback remains clockwise-positive. No X-lock or active
FLOAT transition is part of normal operation.

`PinpointSettings.DIRECTIONS_VERIFIED`, its heading convention, and
`PedroFollowerConfig.MODEL_VERIFIED` are deliberate arming gates. Static pod, Pinpoint, manual-drive,
and characterization work is staged before enabling the disabled line, curve, heading, and template
OpModes. Field observations—not theoretical free speed—must populate the Foresight model.

## Review and verification record

[INTEGRATION_STATUS.md](INTEGRATION_STATUS.md) records the current software checks and remaining physical gates. Tests exercise the actual runtime state machine using an injected host, real pod/controller objects, fake motor boundaries, and a monotonic clock. This covers INIT/Start drift, output authorization, partial delivery, recovery, delayed reads, live caps, fault latching, and cleanup without relying on Android stub methods returning zero.

`DifferentialPod` validates finite combined motor targets, clears stale prepared output, checks phase/Stop/sample age before each write, and stops/latches after direct-call failures. Autonomous and static-angle tests retain the 0.35 combined cap even after live tuning changes; the TeleOp retains its full-scale profile. Cleanup attempts all actions and preserves secondary exceptions. Fault evidence survives close; lifecycle owners cannot be reused.

Pedro 3.0.1 Foresight finishes paths at the parametric endpoint. The configured endpoint timeout/tolerances alone do not enforce FOLLOW accuracy. `PedroPathResult` independently evaluates pose and velocity, and path diagnostics latch failed acceptance. A no-progress check observes path completion, endpoint distance, and heading improvement so a curve moving temporarily away from its endpoint is not mistaken for a stalled robot. Whole-path deadlines remain independent of library state.

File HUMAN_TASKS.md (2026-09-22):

# Human Drivetrain Calibration and Test Tasks

This checklist contains the work that software cannot perform. Complete it on the actual robot and record the results here before enabling powered drive.

Related documentation:

- [README.md](README.md) — operating overview and controls
- [hardware.md](hardware.md) — wiring, specifications, ratios, and commissioning details
- [PROJECT_DESIGN.md](PROJECT_DESIGN.md) — architecture, safety, and design decisions
- [SwervePodEncoder.java](TeamCode/src/main/java/org/firstinspires/ftc/teamcode/SwervePodEncoder.java) — calibration constants to update after review

## Current software gate

Powered `Differential Swerve TeleOp` calibration is enabled after the confirmed encoder and combined-steering checks:

```java
CALIBRATION_VERIFIED = true
LEFT_FORWARD_DEGREES = 13.725   // 0.122 V top-dead-center
RIGHT_FORWARD_DEGREES = 29.025  // 0.258 V top-dead-center
```

Pod calibration and the previously reported low-speed drive tests are accepted. The shared-runtime integration has since changed; repeat powered regressions before normal operation. Pinpoint frame verification is accepted for the commissioned robot; the measured Foresight model remains unverified. Desktop evidence is tracked separately in [INTEGRATION_STATUS.md](INTEGRATION_STATUS.md).

## Safety rules

- Securely raise the robot for all initial motor tests so the wheels cannot contact the floor.
- Keep hands, clothing, cables, and tools clear of the pods and gears.
- Have an operator at the Driver Station and a second person at the robot whenever motors may move.
- Keep the physical battery disconnect or emergency stop accessible.
- Use reduced calibration velocity and stop immediately if a pod moves in the wrong direction, stalls, chatters, or approaches a mechanical limit.
- Use **B** to abort the analog-assisted alignment actions.
- Never assume that a valid 0 V reading proves an analog encoder is connected; 0 V can be a valid encoder position.
- Stop and correct wiring or software signs if a pod moves opposite the expected direction.
- Record results only after the pod has stopped and the reading is stable.

## A. Hardware identity and wiring

### A1. Drive motor identity

- [x] Confirm all four motors are goBILDA `5203-2402-0005`.
- [x] Confirm each motor has the documented 5.2:1 planetary gearbox.
- [x] Confirm the motor encoder wiring follows the matching Control Hub motor port.
- [x] Confirm the physical port/name mapping:

| Port | Program name | Physical location | Confirmed |
|---:|---|---|:---:|
| 0 | `motor0` | Left pod, left motor | [x] |
| 1 | `motor1` | Left pod, right motor | [x] |
| 2 | `motor2` | Right pod, left motor | [x] |
| 3 | `motor3` | Right pod, right motor | [x] |

### A2. Pod quadrature wiring

- [x] Confirm the left Melonbotics encoder quadrature output is on Expansion Hub motor channel 0 and named `encoderleft`.
- [x] Confirm the right Melonbotics encoder quadrature output is on Expansion Hub motor channel 1 and named `encoderright`.
- [x] Confirm both quadrature channels are on the same Expansion Hub.
- [x] Confirm the quadrature hub is separate from the Control Hub carrying the four drive motors.
- [x] Confirm no motor is required to be attached to those Expansion Hub motor channels.
- [x] Confirm the encoder connectors and strain relief cannot contact moving gears. Sensitive positioning wires have ferrite shields and are secured in their ports.

### A3. Pod analog wiring

- [x] Confirm one joiner cable is connected to the Control Hub physical analog connector labeled `0-1`.
- [x] Confirm the left analog signal is channel 0 and named `absencleft`.
- [x] Confirm the right analog signal is channel 1 and named `absencright`.
- [x] Move only the left pod and confirm only `absencleft` changes.
- [x] Move only the right pod and confirm only `absencright` changes.
- [x] Confirm the two signals are not electrically tied together.
- [x] Record connection information shown by the diagnostic tools:

```text
Analog joiner/cable notes: verified
Left analog connection: verified
Right analog connection: verified
Quadrature hub connection: verified
```

## B. Mechanical configuration

### B1. Differential gear assembly

Confirm the installed assembly matches the programmed model:

```text
Each motor: 1:1 bevel pair → 16-tooth → 54-tooth
Each 54-tooth gear is fixed to a 50-tooth gear
Both 50-tooth gears engage the common 19-tooth wheel gear
Left motor: lower differential path
Right motor: upper differential path
```

- [x] Confirm the initial bevel pair for each motor is 1:1.
- [x] Confirm four 16-tooth gears are installed as the driving gears.
- [x] Confirm four 54-tooth gears are installed as the differential gears.
- [x] Confirm each 54-tooth gear is rigidly attached to its 50-tooth gear.
- [x] Confirm the two 50-tooth gears engage the common 19-tooth wheel gear.
- [x] Confirm the right pod is rotated 180° mechanically but is not mirrored.
- [x] Confirm the gears rotate freely without binding through the full allowed pod range.
- [x] Confirm all gear set screws, hubs, shims, and structural fasteners are secure.

### B2. Geometry

- [x] Measure and record wheel diameter:

```text
Measured wheel diameter: 63.25 mm
Code value currently used: 63.25 mm
```

- [x] Measure and record pod wheel-center spacing:

```text
Measured pod spacing: 359.5 mm
Code value currently used: 359.5 mm
```

- [x] Confirm both pods are centered at the documented left/right locations.
- [x] Confirm the installed wheel/tread type and document any difference from the BOM. Installed tread: 40A belt tires from Melonbotics.
- [x] Confirm the wheel does not slip on its 8 mm REX/compatible mounting. Slip occurs only when pushing against an immovable object; additional robot weight is expected to mitigate it.

## C. Motor direction and differential behavior

These checks require the robot to be raised. Use low calibration speed.

### C1. Individual motor sanity

Use the appropriate motor diagnostic procedure and verify that each motor’s physical direction is understood before running the main drive.

| Motor | Expected physical response | Result/notes |
|---|---|---|
| `motor0` | Left pod lower-path motor direction known | joystick up: pod counterclockwise; joystick down: pod clockwise | |
| `motor1` | Left pod upper-path motor direction known | joystick up: pod clockwise; joystick down: pod counterclockwise | |
| `motor2` | Right pod lower-path motor direction known | joystick up: pod counterclockwise; joystick down: pod clockwise | |
| `motor3` | Right pod upper-path motor direction known | joystick up: pod clockwise; joystick down: pod counterclockwise | |

- [x] Confirm all four programmed software directions remain `FORWARD`.
- [x] Record individual motor pod-response directions below.
- [x] Confirm equal positive commands propel the left pod in its directed robot-forward wheel-travel direction.
- [x] Confirm equal positive commands propel the right pod in its directed robot-forward wheel-travel direction.

With both pods facing robot-forward according to their analog-zero references, powering both wheels propels the robot forward.
- [x] Confirm the corrected driver right-stick input steers each pod clockwise/right.
- [x] Confirm right-stick left steers each pod counterclockwise/left.
- [ ] Confirm the right pod’s 180° mounting does not require an additional software mirror or 180° correction.

Record any correction required before proceeding:

```text
Left pod motor sign correction needed:  none / yes: __________
Right pod motor sign correction needed: none / yes: __________
```

## D. Analog forward-reference discovery

Run `Pod Analog Encoder Test`.

Controls:

- **LB** selects left pod.
- **RB** selects right pod.
- **A** commands the selected pod toward its configured target.
- **B** aborts motor-assisted alignment.

Until source constants are populated, the diagnostic targets analog 0°. For initial discovery, manually position each directed wheel-travel axis robot-forward and record the stable displayed analog value. If needed, use the bounded A alignment action only after confirming motor steering direction.

### D1. Left forward reference

- [ ] Select the left pod with LB.
- [ ] Align the left directed wheel-travel axis with robot-forward.
- [ ] Record the stable analog voltage:

```text
Left forward voltage: 0.122 V
```

- [ ] Record the stable raw analog angle shown by telemetry:

```text
Left forward raw degrees: 13.725 °
```

### D2. Right forward reference

- [ ] Select the right pod with RB.
- [ ] Align the right directed wheel-travel axis with robot-forward.
- [ ] Record the stable analog voltage:

```text
Right forward voltage: 0.258 V
```

- [ ] Record the stable raw analog angle shown by telemetry:

```text
Right forward raw degrees: 29.025 °
```

### D3. Analog direction and repeatability

For each pod, rotate slowly clockwise viewed from above and observe whether raw analog angle increases or decreases. Account for wraparound.

| Pod | Clockwise analog behavior | Programmed analog sign | Confirmed |
|---|---|---:|:---:|
| Left | decreases | `-1` | [x] |
| Right | decreases | `-1` | [x] |

- [x] Repeat the forward alignment and confirm it returns extremely close to top dead center for both pods.
- [x] Analog repeatability is accepted as good enough for this application.

```text
Left forward reference spread: very small / accepted
Right forward reference spread: very small / accepted
```

- [x] Confirm the forward reference is acceptable for the intended steering range.

## E. Quadrature channel, sign, and resolution discovery

Run `Swerve Pod Encoder Test`.

Controls:

- **LB/RB** select the left/right pod.
- **A** zeroes the selected quadrature display in software only.
- **X** starts and finishes the full-revolution measurement.
- **Y** steers the selected pod to its configured analog reference.
- **B** aborts alignment.

### E1. Left quadrature

- [ ] Select the left pod.
- [ ] Press A to capture the left software zero.
- [ ] Rotate the left pod exactly 90° clockwise and record signed count delta:

```text
Left CW 90° signed count delta: ______ counts
```

- [ ] Return to the capture point without pressing A again.
- [ ] Press X, rotate the left pod exactly one complete revolution clockwise, and press X again.
- [ ] Record the signed full-revolution count:

```text
Left CW 360° signed count delta: approximately 4100 counts
```

- [x] Confirm magnitude is approximately 4096 raw counts by physical full-revolution measurement; measured approximately 4100 counts, consistent with a 1024 CPR encoder using 4x quadrature decoding.
- [x] Record the quadrature direction result:

```text
Left quadrature sign required: +1 (clockwise increased counts)
```

### E2. Right quadrature

- [ ] Select the right pod.
- [ ] Press A to capture the right software zero.
- [ ] Rotate the right pod exactly 90° clockwise and record signed count delta:

```text
Right CW 90° signed count delta: ______ counts
```

- [ ] Return to the capture point without pressing A again.
- [ ] Press X, rotate the right pod exactly one complete revolution clockwise, and press X again.
- [ ] Record the signed full-revolution count:

```text
Right CW 360° signed count delta: approximately 4100 counts
```

- [x] Confirm magnitude is approximately 4096 raw counts by physical full-revolution measurement; measured approximately 4100 counts, consistent with a 1024 CPR encoder using 4x quadrature decoding.
- [x] Record the quadrature direction result:

```text
Right quadrature sign required: +1 (clockwise increased counts)
```

### E3. Wheel-motion isolation

- [x] Confirmed that rolling the left wheel without rotating the left pod does not change the pod quadrature count.
- [x] Confirmed that rolling the right wheel without rotating the right pod does not change the pod quadrature count.
- [ ] If counts change, stop and inspect mechanical coupling or wiring before enabling drive.

## F. Individual motor direction and differential verification

Run `Individual Motor Drive Test` with the robot raised.

Controls:

```text
D-pad Up:    select motor0
D-pad Right: select motor1
D-pad Down:  select motor2
D-pad Left:  select motor3
Left stick Y: individual motor command, capped at 25% power
LB:           combined left-pod mode
RB:           combined right-pod mode
Left stick Y: combined drive command
Right stick X: combined steering command
Combined output: capped at 420 ticks/s
```

- [x] Raise the robot and confirm only the selected motor moves.
- [x] Record the physical rotation direction of each motor:

```text
motor0 direction:
motor1 direction:
motor2 direction:
motor3 direction:
```

- [ ] Confirm the left motor pair affects only the left pod.
- [ ] Confirm the right motor pair affects only the right pod.
- [ ] Hold LB and verify combined left-pod drive moves the wheel in robot-forward.
- [ ] Hold RB and verify combined right-pod drive moves the wheel in robot-forward.
- [x] Retest right-stick steering after the software polarity correction: right turns clockwise/right and left turns counterclockwise/left on both pods.
- [ ] Confirm equal motor-path motion corresponds to wheel-drive motion.
- [ ] Confirm opposite motor-path motion corresponds to pod-steering motion.
- [ ] Record any sign or assembly mismatch:

```text
Left motor/module observations:
Right motor/module observations:
Differential gear mismatch or binding:
```

## G. Enter calibration values into source

After review, update `SwervePodEncoder.java`:

```java
public static final int LEFT_QUADRATURE_SIGN = ______;
public static final int RIGHT_QUADRATURE_SIGN = ______;
public static final int LEFT_ANALOG_SIGN = -1;
public static final int RIGHT_ANALOG_SIGN = -1;
public static final double LEFT_FORWARD_DEGREES = ______;
public static final double RIGHT_FORWARD_DEGREES = ______;
public static final boolean CALIBRATION_VERIFIED = true;
```

Before setting the final flag:

- [ ] Both forward values are finite and in the range 0° through less than 360°.
- [x] Both analog signs are physically confirmed as `-1`; both voltages decrease clockwise.
- [x] Both quadrature signs are confirmed as `+1` because clockwise rotation increased counts.
- [x] Both full-revolution magnitudes are physically confirmed as approximately 4096 raw counts using the specified power-of-two scale; both measured approximately 4100 counts, consistent with the Melonbotics 1024 CPR encoder and 4x quadrature decoding.
- [ ] Values were independently reviewed by another person.
- [ ] `README.md`, `hardware.md`, and this task file contain the same accepted values.

## H. Main drive INIT alignment

With calibration entered:

- [ ] Build and deploy the current debug APK.
- [ ] Confirm the main drive reports calibration ready.
- [ ] Place both pods away from forward so movement is observable.
- [ ] Press INIT for `Differential Swerve TeleOp` with the robot raised and clear.
- [ ] Confirm both pods automatically steer toward their independent analog forward references before pressing Start.
- [ ] Wait for READY and confirm motor velocity commands are zero while waiting for Start.
- [ ] Press Start and confirm driving begins without repeating alignment.
- [ ] In a separate run, press Start early and confirm driving waits for alignment to finish; verify Stop also cancels during INIT.
- [ ] Confirm alignment telemetry shows each pod's voltage; if feedback is rejected, record the sensor name and voltage from the fault.
- [ ] Confirm both pods stop within the configured alignment tolerance.
- [ ] Confirm the main drive refuses to proceed if a pod cannot align before timeout.
- [ ] Confirm startup requires 100 ms inside tolerance and seeds quadrature with each actual residual analog angle (near zero).
- [ ] Confirm failure of either pod stops both and a completed pod drifting out of tolerance prevents handoff.
- [ ] Restart the robot and repeat at least three times.
- [ ] Confirm the final startup pod-angle error is acceptable:

```text
Left startup error: ______ °
Right startup error: ______ °
Observed issue: one pod sometimes remains at approximately 2–2.1° and never stays below the 2° settling threshold before timeout; retrying or manually repositioning the pods can succeed.
```

## I. Low-speed powered drivetrain test

Run only after sections A–H are complete. Keep the robot raised for the first tests.

### Runtime steering polarity regression check

Reported behavior before the fix: startup analog alignment reached forward, but joystick movement triggered uncontrolled pod steering. Runtime PD used the opposite motor polarity from startup alignment. The corrected runtime loop now shares the startup polarity conversion; chassis rotation input is separately clockwise-positive. Existing measured encoder references, signs, ports, and ratios remain the calibration basis.

For the updated build, verify:

- [ ] After alignment, a small right/left strafe request moves both pods toward the requested wheel axis. `angle / target / error` telemetry should converge toward zero error rather than grow or cycle.
- [ ] Release both sticks: wheel drive becomes zero and pods settle at the retained travel axis without continuous rotation.
- [ ] With pods forward, forward/reverse input rolls the wheels while holding pod angle. Reverse should not require a 180° pod turn.
- [ ] Right-stick right requests clockwise chassis rotation: left wheel forward, right wheel backward. This differs from the diagnostic's right stick, which directly steers a selected pod.

Runtime steering is capped at 0.20 with Kp 0.5, Kd 0.01, and slew rate 2.0/s. Telemetry shows each pod's angle/target/error and both motor velocity targets. A 3° reversal hysteresis band prevents noisy wheel-direction switching near 90°. Low-speed translation, strafing, rotation, combined motion, and stop behavior have been executed and confirmed working on the robot; fault handling and loaded tuning remain pending.

- [x] Forward translation.
- [x] Reverse translation.
- [x] Robot-right strafe.
- [x] Robot-left strafe.
- [x] Clockwise chassis rotation.
- [x] Counterclockwise chassis rotation.
- [x] With translation centered and pods aligned, full right-stick rotation requests full opposite wheel speeds using both motors per pod; logical wheel speeds are opposite. With the right pod negate-and-swap mapping, software predicts approximately +2781 ticks/s on all four hardware motors for clockwise rotation and negative on all four for counterclockwise. Recheck these hardware telemetry signs after the refactor; the earlier opposite-right-motor documentation described logical rather than hardware commands.
- [x] Translation plus clockwise rotation.
- [x] Translation plus counterclockwise rotation.
- [x] Release right stick and confirm zero requested rotation.
- [ ] Confirm pod targets are retained when requested pod velocity is zero.
- [ ] Confirm shortest-path steering reverses wheel direction correctly near 90°.
- [ ] Confirm analog wraparound does not cause an unexpected steering jump.
- [ ] Confirm motor velocities remain within the configured limit.
- [x] Confirm stop behavior sets all four motor velocities to zero.
- [ ] Confirm a transient hub-read failure stops outputs before retrying, reports the recovered-read count, and requires centered sticks before runtime motion resumes.
- [ ] Confirm persistent hub feedback loss or excessive loop delay displays DRIVE STOPPED, holds zero commands, and requires Stop/reinitialization. Record configured hub name, connection, and reason from telemetry/logs.
- [ ] Confirm recovered analog/quadrature disagreement prevents resuming after a hub reset.

Record issues:

```text
Translation behavior:
Rotation behavior:
Combined-motion behavior:
Wrap/shortest-path behavior:
Stopping behavior:
Fault behavior:
```

## J. Loaded drivetrain and tuning validation

These values cannot be established from source code alone.

- [ ] Measure loaded maximum wheel speed.
- [ ] Measure chassis rotation speed.
- [ ] Tune motor velocity PIDF under load.
- [ ] Tune steering Kp.
- [ ] Tune steering Kd.
- [ ] Tune steering slew rate.
- [ ] Tune drive and steering limits for safe operation.
- [ ] Measure stopping distance and time.
- [ ] Check motor and gearbox temperature after repeated operation.
- [ ] Check battery voltage sag and current draw.
- [ ] Check gear wear, loosened fasteners, tread slip, and structural flex.
- [ ] Confirm the robot remains controllable if one pod is temporarily unloaded.
- [ ] Document final accepted tuning values in `hardware.md` and this file.

## K. Completion gate

The current drivetrain is ready for normal operation only when all are true:

- [x] Hardware names and ports match the software.
- [x] Differential gear assembly matches the documented topology.
- [x] Individual motor directions are recorded; combined pod steering signs still require confirmation.
- [x] Analog forward references are recorded: left 0.122 V / 13.725°, right 0.258 V / 29.025°.
- [x] Analog signs are recorded as `-1` for both pods.
- [x] Quadrature signs are recorded as `+1` for both pods.
- [x] Full-revolution quadrature scale is accepted as 4096 counts.
- [x] Calibration constants are entered and reviewed.
- [x] `CALIBRATION_VERIFIED` is true.
- [ ] Startup alignment succeeds repeatedly.
- [x] Low-speed drive tests pass.
- [ ] Stop and fault behavior pass.
- [ ] Loaded speed, thermal, current, and tuning checks are documented.

## Final accepted values

Keep this section synchronized with `SwervePodEncoder.java` and `hardware.md` after commissioning.

```text
Left forward analog voltage: 0.122 V
Left forward raw degrees:    13.725 °
Right forward analog voltage: 0.258 V
Right forward raw degrees:    29.025 °
Left analog sign:             -1
Right analog sign:            -1
Left quadrature sign:         +1
Right quadrature sign:        +1
Left full-revolution counts:  approximately 4100 measured; 4096 configured
Right full-revolution counts: approximately 4100 measured; 4096 configured
Measured wheel diameter:      63.25 mm
Measured pod spacing:         359.5 mm
Final steering KP:             ______
Final steering KD:             ______
Final motor PIDF:              ______
Final safe drive limit:        ______
Final safe steering limit:     ______
Commissioned by:              ______
Commission date:               ______
```

## Pedro integration commissioning gates

Do these in order. Do not enable the disabled path OpModes or set a verification flag from an
assumption.

- [x] Run **Pinpoint Encoder Direction Test** without drivetrain power. Raw forward-X and left-Y
  signs are accepted for the commissioned hardware.
- [x] Run **Pinpoint Pose Test** with the labeled candidate directions. READY, forward +X, left +Y,
  CCW-positive heading/rate, and field-frame translation are accepted.
- [x] Measure 24 in forward and left and rotation behavior. Results are accepted for the current
  robot configuration and recorded in `hardware.md`; `PinpointSettings` is commissioned.
- [ ] Run **Pedro Pod Angle Test** one selected pod at a time at 0°, ±45°, ±90°, and wrap-adjacent
  ±179°. Confirm no positive feedback, reversal chatter, nonselected hardware access, or FLOAT.
- [ ] Re-run the established reduced-limit TeleOp forward/reverse/strafe/turn/combined/release/Stop
  checks after the shared-runtime refactor.
- [ ] Run **Pedro Manual Drive Test** robot-centrically at headings 0 and +90°. Confirm release sends
  true zero and BRAKE remains active.
- [ ] Run **Pedro Drive Characterization** in both directions. Record loaded X/Y speed, BRAKE
  deceleration/displacement, rotation response, battery voltage, and the `0.15` drive scale.
- [ ] Fit the linear/quadratic translation and heading braking models; enter finite measured values
  in `PedroFollowerConfig`, verify requested 6 in/s² does not exceed natural deceleration, and only
  then set `MODEL_VERIFIED`.
- [ ] Enable and run the 12 in line tests at 8 in/s or lower, then 24 in. Record endpoint error,
  completion reason, deadline behavior, saturation, and zero/BRAKE finish.
- [ ] Enable broad constant-heading curves, reverse traversal, then ±45°/±90° heading changes and
  wrap crossings. Change only one speed, acceleration, or gain variable at a time.
- [ ] Inject/read-test recovered and persistent hub failures, bad Pinpoint status, nonfinite state,
  >250 ms loops, partial output failure, and Stop in INIT/FOLLOW/HOLD. Confirm all motors are stopped
  and cache modes restore.

### Characterization record

```text
Drive scale:                         0.15
Battery voltage(s):                  ______
Max loaded forward velocity (in/s):  ______
Max loaded reverse velocity (in/s):  ______
Max loaded left velocity (in/s):     ______
Max loaded right velocity (in/s):    ______
Natural forward deceleration:        ______
Natural strafe deceleration:         ______
Forward linear/quadratic brake fit:  ______ / ______
Strafe linear/quadratic brake fit:   ______ / ______
Heading linear/quadratic brake fit:  ______ / ______
Recorded by/date:                    ______
```

### Collecting characterization data

Use one commanded axis at a time, in both directions, at several speeds and battery levels. Hold until steady speed, release every control for true zero/BRAKE, and keep recording until stopped. `Pedro Drive Characterization` produces timestamped signed CSV under `PedroCharacterization`, with body X/Y velocity in in/s, angular rate in rad/s, field pose, input commands, battery volts, and drive scale. Capture with `adb logcat -v raw -s PedroCharacterization:I '*:S'` or export the Robot Controller log. Keep CSV records with the commissioning observations.

For each release, use the last driven sample as the initial body velocity, then measure displacement until rest. Rotate field displacement into the release-time robot frame; unwrap heading changes. Fit forward and strafe displacement with `d = linear * v + quadratic * v * abs(v)` separately, and the equivalent heading model in radians. Use multiple samples, inspect residuals, and verify both directions. Estimate natural deceleration from the released velocity trace using zero commanded velocity and BRAKE. Enter positive diagonal coefficients, measured speed limits, and natural deceleration in `PedroFollowerConfig`; record `CHARACTERIZED_DRIVE_SCALE` as an independent measured setting. It must equal the active autonomous scale. Do not use the test-only synthetic model as a hardware fit.

### Refactor regression and endpoint acceptance

- [ ] Recheck graphable motor target/measured/count and pod angle/rate/analog series on Dashboard.
- [ ] Recheck all four hardware target signs during pure clockwise/CCW rotation with pods forward.
- [ ] Confirm completely centered controls command true zero; no active steering remains at zero chassis demand.
- [ ] Verify the selected-pod diagnostic catches delayed/failed feedback and stops before allowing another command; the other pod motors and Pinpoint remain untouched.
- [ ] Record `Completion reason` and actual terminal pose/velocity for every path run. `END_WITHIN_TOLERANCE` requires <=0.5 in, <=3 degrees, <=1 in/s, and <=5 degrees/s. `END_OUTSIDE_TOLERANCE` is a failed run even if Pedro stopped FOLLOW normally.
- [ ] If repeated parametric completion misses heading/velocity tolerances, tune the trajectory/model and heading interpolation before enabling competition autonomous. Pedro 3.0.1's endpoint flags alone do not certify pose accuracy.

Software tests and successful builds do not mark any of these physical checks complete.

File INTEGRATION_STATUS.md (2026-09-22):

# Integration status and verification

Reviewed September 21, 2026 against [the implementation plan](../PedroSwerving/PEDRO_INTEGRATION_PLAN.md).

The software integration is implemented, desktop-tested, and builds with both local Pedro artifacts and published 3.0.1. Pinpoint direction and heading commissioning has been accepted for the current robot configuration. Foresight model characterization remains a separate gate before path autonomy.

## Verification evidence

| Check | Result |
| --- | --- |
| Pedro `:core:test` | 7 compatibility-contract tests passed |
| Pedro `:core:spotlessCheck` | Passed |
| Pedro `:revhub:assembleRelease` | Release AAR built |
| Pedro `:revhub:lintRelease` | Passed, no lint issues |
| Robot `:TeamCode:lintDebug` | Passed; dependency native-library alignment and unused SDK resource warnings remain |
| Robot against local Pedro JAR/AAR | 103 unit tests passed; debug APK assembled, including D8 and duplicate-class checks |
| Robot against published Pedro 3.0.1 | 103 unit tests passed; debug APK assembled, including D8 and duplicate-class checks |
| Runtime dependency graph | `core:3.0.1`, `revhub:3.0.1`, Kotlin stdlib 2.3.21; FTC artifacts remain 12.0.0 |

Tests include the existing control/encoder/snapshot suite plus both-pod motor mapping, live autonomous caps, zero/BRAKE behavior, initialization cancellation, fresh Start drift, partial initialization/output failure, fault latching, loop overruns, hub recovery, guarded Pinpoint status/timing/finite values, explicit/default follower timing, Foresight frame conversion, and terminal accuracy classification. The runtime tests inject a host and motor boundaries into the actual state machine; they do not need Android stub methods to imitate hardware.

Warnings remain for Java 8 source/target on JDK 21 and legacy Gradle APIs used by the existing build plugins/FTC build. Robot lint also identifies 16 KB alignment in bundled FTC/OpenFTC native libraries and unused SDK resources. These dependency warnings were retained without changing the pinned FTC stack; compatibility with an Android device requiring 16 KB native-library pages is not established. No wrapper, FTC SDK, or compile SDK upgrade was needed. Same-thread software cannot interrupt a blocked SDK call or guarantee delivery of a failed motor stop; physical fault injection is still required.

## Reproduce

Configure each repository's `local.properties` or `ANDROID_HOME` for the Android SDK. Pedro builds with platform 35; the robot retains compile SDK 30. Use JDK 21 locally (the robot already has daemon criteria for JDK 21); Java source/target remain 8.

From the Pedro repository on Windows:

```powershell
./scripts/verify-projects.ps1 -BuildJdk 'YOUR_JDK_21_DIRECTORY'
```

The script verifies Pedro, runs robot checks against local artifacts, then restores the default published dependency for the final APK/reports. Its `-RobotRepo` parameter supports arbitrary checkout locations. It does not publish or install anything on the robot.

Equivalent individual commands:

```powershell
# Pedro checkout
./gradlew.bat :core:test :core:jar :core:spotlessCheck :revhub:assembleRelease :revhub:lintRelease
# Robot checkout: the property points to the Pedro checkout, after the preceding build.
./gradlew.bat '-PpedroLocalArtifacts=../PedroSwerving' :TeamCode:testDebugUnitTest :TeamCode:assembleDebug
# Normal deployment build: omit the property to use published 3.0.1.
./gradlew.bat :TeamCode:testDebugUnitTest :TeamCode:assembleDebug :TeamCode:lintDebug
```

On Unix replace `./gradlew.bat` with `./gradlew`. `pedroLocalArtifacts` is optional and replaces both Pedro modules with local files for that invocation; it does not append duplicate classes or import Pedro build plugins. Rebuild local artifacts before using this option. Normal published builds need only the robot checkout.

Outputs:

- Robot APK: `TeamCode/build/outputs/apk/debug/TeamCode-debug.apk` (the exact output name is listed by `output-metadata.json`).
- Robot tests: `TeamCode/build/reports/tests/testDebugUnitTest/index.html`.
- Pedro tests: `core/build/reports/tests/test/index.html`.
- Pedro library: `revhub/build/outputs/aar/revhub-release.aar` and `core/build/libs/core-3.0.1.jar`.
- Dependency inspection: `./gradlew.bat :TeamCode:dependencies --configuration debugRuntimeClasspath`.

## Ownership and behavior

| Source | Responsibility |
| --- | --- |
| `DifferentialSwerveRuntime` | INIT/READY/ARMED/fault/Stop state, sample timing, output authorization, autonomous cancellation and TeleOp recovery |
| `DifferentialSwerveHardware`, `SwerveHubSession`, `Cleanup` | SDK acquisition, changed-value PIDF, validated bulk snapshots, independent cleanup attempts/cache restoration |
| `DifferentialPod` | Existing encoder/alignment/controller composition, one right-pod negate-and-swap, per-write authorization, finite output cap, immediate zero |
| `DifferentialSwerveDrivetrain`, `PedroSwerveMath` | Forward/left/CCW contract, existing kinematics, linear wheel-envelope allocator, zero/BRAKE policy |
| `GuardedPinpointLocalizer`, `PinpointSettings` | Shared sensor configuration, stationary calibration, READY/timing/finite-state checks, one update per follower cycle |
| `SafePedroFollower`, `PedroAutoDrive` | Normal Pedro API under a guarded cycle, immediate stop, fault cancellation, cleanup-protected lifetime, disarmed model validation |
| `PedroFollowerConfig`, `ManualOnlyAlgorithm` | Complete model/configuration validation; manual commissioning before path-model approval |
| `PedroPathResult`, `PedroPathTestBase` | Independent terminal acceptance, 10-second deadline and 2-second no-progress detection after steering allowance |
| `DifferentialSwerveTeleOp` | Existing radial/cubic input shaping, full-scale TeleOp profile, neutral recovery, numeric Dashboard diagnostics |
| Pedro commissioning OpModes | Selected-pod static angles; manual drive; signed characterization logs; disabled line/curve/heading/template paths |

All primary sources are under `TeamCode/src/main/java/org/firstinspires/ftc/teamcode`; unit tests are under the matching `src/test/java` package.

The robot's coordinate contract is X forward, Y left, yaw CCW, inches/radians. The calibrated pod tracker stays CW-positive internally. Conversion occurs exactly once at the drivetrain boundary. The published generic `Swerve` is intentionally unused: its FLOAT and cosine-scaling behavior conflicts with this robot's lifecycle and controller.

Nonzero outputs require the correct phase and a fresh sample, checked again before each motor write. Direct pod failures also stop and latch the owning runtime. Completely zero chassis demand clears steering output and commands zero velocity; an individual zero-speed pod in a moving chassis retains its target. TeleOp uses its established 1.0 drive profile; autonomous uses 0.15 drive, 0.20 turn envelope, and 0.35 combined motor cap. Live tuning cannot bypass that cap. Startup alignment has a 2-degree tolerance, 100 ms settle, and 5-second deadline.

Runtime reads retry at most three times within 150 ms, stopping before retries. Loops/sample ages above 250 ms fail closed. TeleOp waits for neutral controls after recovery; autonomous and the armed static-angle diagnostic cancel. Analog feedback seeds the tracker and checks recovery; runtime azimuth remains quadrature-only.

## Published follower behavior

`Follower.stop()` in Pedro 3.0.1 only changes state; the robot's `SafePedroFollower.stop()` sends immediate motor zero. Both `update()` overloads acquire fresh hardware feedback. An explicit delta affects algorithm timing only, never the hardware clock or output-age checks. A skipped-output cycle, including FOLLOW-to-HOLD transition, cannot leave a previous command active.

Foresight advances at the parametric endpoint even if terminal heading or velocity is outside configured tolerances. `isBusy()` is not a complete lifecycle signal, and `distanceToEndpoint()` becomes zero after the tracker is cleared. The path tests retain the requested endpoint and evaluate actual pose/velocity independently. Acceptance requires <=0.5 in translation, <=3 degrees heading, <=1 in/s translation speed, and <=5 degrees/s angular speed. Outside-tolerance/invalid completion latches a fault. The overall deadline is independent of `timeoutConstraint` (milliseconds). These diagnostics report accuracy; they do not automatically add an uncommissioned final pose-hold maneuver.

## Physical work still required

Follow [HUMAN_TASKS.md](HUMAN_TASKS.md), preserving its actual measurement records:

1. Repeat INIT/Start/Stop and low-speed TeleOp regressions after the shared-runtime refactor; verify Dashboard signals and hardware motor signs.
2. Pinpoint X/Y directions, CCW heading/rate, field frame, distance scale, and rotation behavior are accepted for the current robot configuration; retain monitoring during Pedro manual commissioning.
3. Run selected-pod static angles, then bounded Pedro manual drive, including delayed/failed feedback and release-to-zero behavior.
4. Capture characterization CSV, fit loaded speed/deceleration/braking models in the documented units, and enter the independent recorded drive scale. Set `MODEL_VERIFIED` only after those records exist.
5. Enable one disabled path diagnostic at a time: lines, curves, heading changes and wrap cases. Record completion reasons, terminal error/velocity, saturation, battery condition, and repeatability before enabling the template for competition.

`DIRECTIONS_VERIFIED=true` and the heading convention is `COUNTERCLOCKWISE_POSITIVE` for the commissioned robot. `MODEL_VERIFIED=false` and the `@Disabled` path annotations remain intentional until measured Foresight characterization is entered.

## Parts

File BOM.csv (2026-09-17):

Vendor | Item | SKU | Unit Price | Quantity | Line Total
Melonbotics | Through Bore Encoder |  | $38.99 | 2 | $77.98
Melonbotics | 45A Rubber Wheel Tread (180-3M 15mm wide) |  | $4.99 | 2 | $9.98
goBILDA | 5203-2402-0005 Yellow Jacket Motor 1150 RPM | 5203-2402-0005 |  | 4
goBILDA | MOD 0.8 16-Tooth Drive Gear |  |  | 4
goBILDA | MOD 0.8 54-Tooth Differential Gear |  |  | 4
goBILDA | MOD 0.8 50-Tooth Wheel Bevel Gear |  |  | 4
goBILDA | MOD 0.8 19-Tooth Wheel Gear |  |  | 2
goBILDA | 2807 Series Stainless Steel Shim (4mm ID x 7mm OD 0.25mm Thickness 12-Pack) | 2807-0407-0250 | $1.72 | 1 | $1.72
goBILDA | 48mm Omni Wheel (8mm REX Bore 50A Durometer) | 3624-4008-0048 | $12.74 | 4 | $50.96
goBILDA | GripForce Gecko Wheel (8mm REX Bore 48mm Diameter) | 3613-4008-0048 | $5.99 | 4 | $23.96
Limelight Vision | Limelight 3A |  | $189.00 | 1 | $189.00
AndyMark | Gray Grippy Tread 1 in. Wide 10 ft. Long | am-2611a | $25.00 | 1 | $25.00
Melonbotics | Tax (5.5%) |  |  |  | $4.84
Melonbotics | Shipping |  |  |  | $8.80
goBILDA | Tax (5.5%) |  |  |  | $9.66
goBILDA | Shipping |  |  |  | $11.99
Limelight Vision | Tax (5.5%) |  |  |  | $10.40
Limelight Vision | Shipping |  |  |  | $23.54
AndyMark | Tax (5.5%) |  |  |  | $1.38
AndyMark | Shipping |  |  |  | $11.99

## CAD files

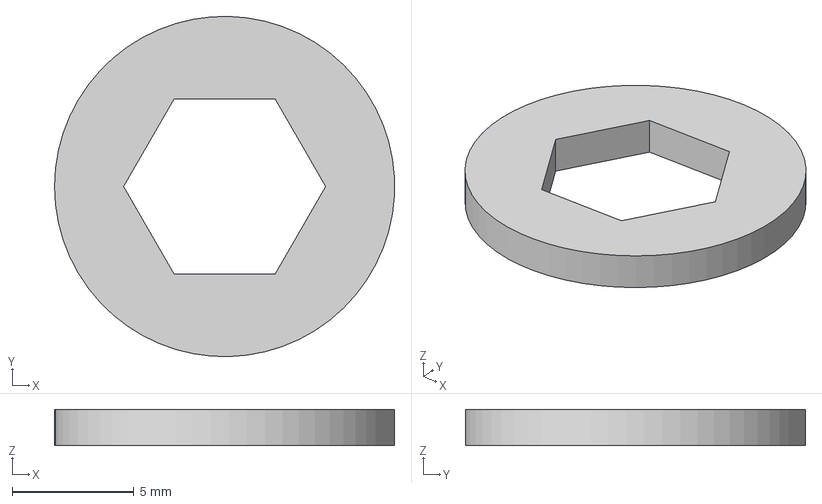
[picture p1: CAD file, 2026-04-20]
dummy cad.step
14.0 x 14.0 x 1.50 mm

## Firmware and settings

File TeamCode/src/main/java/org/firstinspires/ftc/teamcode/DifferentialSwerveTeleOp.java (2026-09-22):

package org.firstinspires.ftc.teamcode;

import com.acmerobotics.dashboard.FtcDashboard;
import com.acmerobotics.dashboard.telemetry.MultipleTelemetry;
import com.pedropathing.drivetrain.DrivePowers;
import com.qualcomm.robotcore.eventloop.opmode.LinearOpMode;
import com.qualcomm.robotcore.eventloop.opmode.TeleOp;
import com.qualcomm.robotcore.util.RobotLog;

import java.util.Map;

/** Established robot-centric TeleOp, now using the shared drivetrain lifecycle and safety gate. */
@TeleOp(name = "Differential Swerve TeleOp", group = "Differential Swerve")
public class DifferentialSwerveTeleOp extends LinearOpMode {
    private static final int TELEMETRY_INTERVAL_MS = 100;

    @Override
    public void runOpMode() {
        DifferentialSwerveRuntime runtime = new DifferentialSwerveRuntime(this, false);
        try {
            telemetry = new MultipleTelemetry(telemetry, FtcDashboard.getInstance().getTelemetry());
            telemetry.setMsTransmissionInterval(TELEMETRY_INTERVAL_MS);
            telemetry.addLine("ROBOT-CENTRIC: left stick = translation, right stick X = turn.");
            telemetry.addLine("INIT aligns both pods to forward. Keep clear while they move.");
            telemetry.update();
            if (!runtime.initializeAndAlign()) return;
            DifferentialSwerveDrivetrain drivetrain = new DifferentialSwerveDrivetrain(runtime, false);

            telemetry.addLine("READY — pods aligned. Press Start to drive.");
            telemetry.update();
            waitForStart();
            if (isStopRequested()) return;
            runtime.arm();

            SwerveDriverInput input = new SwerveDriverInput();
            boolean waitingForNeutral = false;
            long nextTelemetry = 0L;
            while (opModeIsActive()) {
                DifferentialSwerveRuntime.Cycle cycle = runtime.beginHardwareCycle();
                try {
                    input.update(gamepad1.left_stick_x, gamepad1.left_stick_y, gamepad1.right_stick_x);
                    if (cycle.recovered) waitingForNeutral = true;
                    if (waitingForNeutral) {
                        boolean nonNeutral = input.getForward() != 0.0
                                || input.getStrafe() != 0.0 || input.getTurn() != 0.0;
                        if (!nonNeutral) waitingForNeutral = false;
                    } else {
                        drivetrain.drive(new DrivePowers(
                                input.getForward(), -input.getStrafe(),
                                -input.getTurn() / SwerveDriverInput.MAX_TURN_RATE), true);
                    }
                } finally {
                    runtime.finishCycle();
                }

                long now = System.nanoTime();
                if (now >= nextTelemetry) {
                    nextTelemetry = now + TELEMETRY_INTERVAL_MS * 1_000_000L;
                    telemetry.addLine(waitingForNeutral
                            ? "Hub feedback recovered. Center both sticks to resume."
                            : "ROBOT-CENTRIC");
                    telemetry.addData("Forward / right / CW rad/s", "%.2f / %.2f / %.2f",
                            input.getForward(), input.getStrafe(), input.getTurn());
                    showPod("Left", runtime.leftPod().debug());
                    showPod("Right", runtime.rightPod().debug());
                    telemetry.addData("Loop (ms)", "%.1f", cycle.seconds * 1000.0);
                    runtime.showHubHealth();
                    telemetry.update();
                }
            }
        } catch (RuntimeException exception) {
            runtime.latchFault(exception.getMessage());
            RobotLog.ee("DifferentialSwerve", "TeleOp stopped: " + exception);
            while (!isStopRequested()) {
                telemetry.addLine("DRIVE STOPPED — feedback/control fault. Stop and reinitialize.");
                telemetry.addData("Fault", runtime.fault());
                telemetry.update();
                sleep(TELEMETRY_INTERVAL_MS);
            }
        } finally {
            runtime.close();
        }
    }

    private void showPod(String name, Map<String, Object> data) {
        int firstMotor = "Right".equals(name) ? 2 : 0;
        telemetry.addData("motor" + firstMotor + " target (ticks/s)", data.get("firstTargetTicks"));
        telemetry.addData("motor" + (firstMotor + 1) + " target (ticks/s)", data.get("secondTargetTicks"));
        telemetry.addData("motor" + firstMotor + " measured (ticks/s)", data.get("firstMeasuredTicks"));
        telemetry.addData("motor" + (firstMotor + 1) + " measured (ticks/s)", data.get("secondMeasuredTicks"));
        telemetry.addData("motor" + firstMotor + " count", data.get("firstCount"));
        telemetry.addData("motor" + (firstMotor + 1) + " count", data.get("secondCount"));
        telemetry.addData(name + " requested speed (normalized)", data.get("requestedDrive"));
        telemetry.addData(name + " drive command", data.get("driveCommand"));
        telemetry.addData(name + " steer command", data.get("steeringCommand"));
        telemetry.addData(name + " angle error (deg)", Math.toDegrees((double) data.get("errorRad")));
        telemetry.addData(name + " quadrature count", data.get("rawCount"));
        telemetry.addData(name + " quadrature angle (deg)", Math.toDegrees((double) data.get("actualEncoderRad")));
        telemetry.addData(name + " pod rate (deg/s)", Math.toDegrees((double) data.get("rateRadPerSec")));
        telemetry.addData(name + " absolute voltage", data.get("absoluteVolts"));
        telemetry.addData(name + " absolute angle (deg)", Math.toDegrees((double) data.get("absoluteAngleRad")));
        telemetry.addData(name + " quadrature minus absolute (deg)",
                Math.toDegrees((double) data.get("quadratureMinusAbsoluteRad")));
        telemetry.addData(name + " angle / target / error (deg)", "%.1f / %.1f / %.1f",
                Math.toDegrees((double) data.get("actualEncoderRad")),
                Math.toDegrees((double) data.get("optimizedTargetRad")),
                Math.toDegrees((double) data.get("errorRad")));
        telemetry.addData(name + " drive / steer", "%.3f / %.3f",
                (double) data.get("driveCommand"), (double) data.get("steeringCommand"));
        telemetry.addData(name + " quadrature / absolute V", "%s / %.4f",
                data.get("rawCount"), (double) data.get("absoluteVolts"));
        telemetry.addData(name + " rate / quad-absolute (deg)", "%.1f deg/s / %.1f deg",
                Math.toDegrees((double) data.get("rateRadPerSec")),
                Math.toDegrees((double) data.get("quadratureMinusAbsoluteRad")));
        telemetry.addData(name + " hardware targets", "%.0f / %.0f",
                (double) data.get("firstTargetTicks"), (double) data.get("secondTargetTicks"));
        telemetry.addData(name + " measured ticks/s", "%.0f / %.0f",
                (double) data.get("firstMeasuredTicks"), (double) data.get("secondMeasuredTicks"));
        telemetry.addData(name + " module speed (m/s)", "%.3f",
                (double) data.get("moduleSpeedMetersPerSecond"));
    }
}

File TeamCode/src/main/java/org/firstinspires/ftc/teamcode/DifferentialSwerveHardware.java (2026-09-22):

package org.firstinspires.ftc.teamcode;

import com.qualcomm.robotcore.eventloop.opmode.LinearOpMode;
import com.qualcomm.robotcore.hardware.AnalogInput;
import com.qualcomm.robotcore.hardware.DcMotor;
import com.qualcomm.robotcore.hardware.DcMotorEx;
import com.qualcomm.robotcore.hardware.DcMotorSimple;
import com.qualcomm.robotcore.util.RobotLog;
import java.util.ArrayList;
import java.util.List;

/** FTC SDK boundary. Runtime state and fault tests use the same lifecycle with a fake host. */
final class DifferentialSwerveHardware implements DifferentialSwerveRuntime.Host {
    private static final String TAG = "DifferentialSwerve";
    private final LinearOpMode opMode;
    private final DcMotorEx[] motors = new DcMotorEx[4];
    private final SwerveHubSession hubs;
    private DifferentialPod leftPod;
    private DifferentialPod rightPod;
    private double appliedP = Double.NaN, appliedI = Double.NaN, appliedD = Double.NaN, appliedF = Double.NaN;

    DifferentialSwerveHardware(LinearOpMode opMode) {
        this.opMode = opMode;
        this.hubs = new SwerveHubSession(opMode.hardwareMap, opMode::isStopRequested);
    }

    @Override public DifferentialPod[] initialize(DifferentialPod.OutputGate gate, double maxDrive,
                                                  double maxMotorCommand) {
        initializeHardware(gate, maxDrive, maxMotorCommand);
        hubs.initialize();
        return new DifferentialPod[] {leftPod, rightPod};
    }

    private void initializeHardware(DifferentialPod.OutputGate gate, double maxDrive, double maxMotorCommand) {
        String[] names = {HardwareConstants.MOTOR_LEFT_POD_LEFT, HardwareConstants.MOTOR_LEFT_POD_RIGHT,
                HardwareConstants.MOTOR_RIGHT_POD_LEFT, HardwareConstants.MOTOR_RIGHT_POD_RIGHT};
        for (int i = 0; i < motors.length; i++) {
            motors[i] = opMode.hardwareMap.get(DcMotorEx.class, names[i]);
            motors[i].setVelocity(0.0);
            motors[i].setZeroPowerBehavior(DcMotor.ZeroPowerBehavior.BRAKE);
            motors[i].setDirection(DcMotorSimple.Direction.FORWARD);
            motors[i].setMode(DcMotor.RunMode.RUN_USING_ENCODER);
            if (motors[i].getPortNumber() != i || motors[i].getController() != motors[0].getController()) {
                throw new IllegalArgumentException("Configure motor0..motor3 on Control Hub ports 0..3");
            }
        }
        DcMotor leftQuadrature = opMode.hardwareMap.get(DcMotor.class, HardwareConstants.ENCODER_LEFT);
        DcMotor rightQuadrature = opMode.hardwareMap.get(DcMotor.class, HardwareConstants.ENCODER_RIGHT);
        if (leftQuadrature.getPortNumber() != 0 || rightQuadrature.getPortNumber() != 1
                || leftQuadrature.getController() != rightQuadrature.getController()
                || leftQuadrature.getController() == motors[0].getController()) {
            throw new IllegalArgumentException(
                    "Configure encoderleft/encoderright on separate Expansion Hub ports 0/1");
        }
        AnalogInput leftAbsolute = opMode.hardwareMap.get(AnalogInput.class, HardwareConstants.ANALOG_LEFT);
        AnalogInput rightAbsolute = opMode.hardwareMap.get(AnalogInput.class, HardwareConstants.ANALOG_RIGHT);
        leftPod = DifferentialPod.forHardware("leftPod", false, motors[0], motors[1],
                leftQuadrature, leftAbsolute, maxDrive, maxMotorCommand, gate);
        rightPod = DifferentialPod.forHardware("rightPod", true, motors[2], motors[3],
                rightQuadrature, rightAbsolute, maxDrive, maxMotorCommand, gate);
        leftPod.setToBreak();
        rightPod.setToBreak();
        applyMotorPidfIfChanged();
    }

    @Override public String refreshHubs() { return hubs.refresh(); }

    public void applyMotorPidfIfChanged() {
        SwerveTuning.validate();
        double p = SwerveTuning.MOTOR_VELOCITY_P;
        double i = SwerveTuning.MOTOR_VELOCITY_I;
        double d = SwerveTuning.MOTOR_VELOCITY_D;
        double f = SwerveTuning.MOTOR_VELOCITY_F;
        if (p == appliedP && i == appliedI && d == appliedD && f == appliedF) return;
        for (DcMotorEx motor : motors) {
            if (motor != null) motor.setVelocityPIDFCoefficients(p, i, d, f);
        }
        appliedP = p;
        appliedI = i;
        appliedD = d;
        appliedF = f;
    }
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

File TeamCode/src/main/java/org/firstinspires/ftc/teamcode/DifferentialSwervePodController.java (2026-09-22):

package org.firstinspires.ftc.teamcode;

/** Hardware-independent, clockwise-positive pod control and differential motor mixing. */
public final class DifferentialSwervePodController {
    // Start with bounded steering comparable to the working analog alignment loop.
    public static final double DEFAULT_KP = 0.5;
    public static final double DEFAULT_KD = 0.01;
    public static final double DEFAULT_MAX_STEER = 0.20;
    public static final double DEFAULT_SLEW_RATE = 2.0;
    private static final double REVERSAL_HYSTERESIS = Math.toRadians(3.0);

    private boolean reversed;
    private boolean hasTarget;
    private double steeringCommand;
    private double angleError;
    private double optimizedTargetAngle;
    private double leftMotorCommand;
    private double rightMotorCommand;

    /**
     * The measured motor response is CCW for left-positive/right-negative.
     * Convert a CW-positive correction to the steering term in left=drive+steer,
     * right=drive-steer. Sensor signs and chassis rotation do not belong here.
     */
    public static double motorSteeringForClockwise(double clockwiseCommand) {
        return -clockwiseCommand;
    }

    public void update(double currentAngle, double measuredRate, double targetAngle,
                       double targetSpeed, double seconds, double kp, double kd,
                       double maxDrive, double maxSteer, double slewRate) {
        angleError = SwervePodEncoder.wrapRadians(targetAngle - currentAngle);
        if (!hasTarget) {
            reversed = Math.abs(angleError) > Math.PI / 2.0;
            hasTarget = true;
        } else if (Math.abs(angleError) > Math.PI / 2.0 + REVERSAL_HYSTERESIS) {
            reversed = true;
        } else if (Math.abs(angleError) < Math.PI / 2.0 - REVERSAL_HYSTERESIS) {
            reversed = false;
        }
        // Keep the chosen wheel direction through small encoder/stick noise near 90 degrees.
        if (reversed) {
            angleError = SwervePodEncoder.wrapRadians(angleError + Math.PI);
            targetSpeed = -targetSpeed;
        }
        optimizedTargetAngle = SwervePodEncoder.wrapRadians(currentAngle + angleError);

        // Both P and measured-rate damping are in the encoder's CW-positive frame.
        // Convert the ENTIRE PD correction, so D opposes rather than reinforces motion.
        double steerLimit = clamp(maxSteer, 0.0, 1.0);
        double requestedSteering = clamp(motorSteeringForClockwise(
                kp * angleError - kd * measuredRate), -steerLimit, steerLimit);
        if (slewRate > 0.0) {
            double step = slewRate * seconds;
            requestedSteering = clamp(requestedSteering,
                    steeringCommand - step, steeringCommand + step);
        }
        // A reduced limit must take effect even if the previous slew state was larger.
        steeringCommand = clamp(requestedSteering, -steerLimit, steerLimit);

        double alignment = Math.max(0.0, Math.cos(angleError));
        double drive = targetSpeed * alignment * alignment * clamp(maxDrive, 0.0, 1.0);
        double driveHeadroom = 1.0 - Math.abs(steeringCommand);
        drive = clamp(drive, -driveHeadroom, driveHeadroom);
        leftMotorCommand = drive + steeringCommand;
        rightMotorCommand = drive - steeringCommand;
        if (!Double.isFinite(leftMotorCommand) || !Double.isFinite(rightMotorCommand)) {
            throw new IllegalArgumentException("Nonfinite motor command; check tuning values");
        }
    }

    public double getAngleError() { return angleError; }
    public boolean isReversed() { return reversed; }

    /** Match software slew state to an externally commanded motor stop. Retain target choice. */
    public void stopOutput() {
        steeringCommand = 0.0;
        leftMotorCommand = 0.0;
        rightMotorCommand = 0.0;
    }
    public double getOptimizedTargetAngle() { return optimizedTargetAngle; }
    public double getSteeringCommand() { return steeringCommand; }
    public double getLeftMotorCommand() { return leftMotorCommand; }
    public double getRightMotorCommand() { return rightMotorCommand; }

    private static double clamp(double value, double min, double max) {
        return Math.max(min, Math.min(max, value));
    }
}

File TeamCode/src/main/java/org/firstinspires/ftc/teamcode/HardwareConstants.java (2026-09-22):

package org.firstinspires.ftc.teamcode;

/**
 * Shared hardware constants for differential swerve drivetrain.
 * Eliminates duplication across OpModes and provides single source of truth.
 */
public final class HardwareConstants {
    
    // Prevent instantiation of utility class
    private HardwareConstants() {
        throw new UnsupportedOperationException("HardwareConstants is a utility class and cannot be instantiated");
    }
    
    // ==================== HARDWARE NAMES ====================
    // Control Hub motor ports
    public static final String MOTOR_LEFT_POD_LEFT = "motor0";
    public static final String MOTOR_LEFT_POD_RIGHT = "motor1";
    public static final String MOTOR_RIGHT_POD_LEFT = "motor2";
    public static final String MOTOR_RIGHT_POD_RIGHT = "motor3";
    
    // Expansion Hub encoder ports (motor channels 0/1, read-only)
    public static final String ENCODER_LEFT = "encoderleft";
    public static final String ENCODER_RIGHT = "encoderright";
    
    // Control Hub analog ports (from SwervePodEncoder)
    public static final String ANALOG_LEFT = "absencleft";
    public static final String ANALOG_RIGHT = "absencright";
    
    // ==================== MOTOR SPECIFICATIONS ====================
    public static final double MOTOR_FREE_SPEED_RPM = 1150.0;
    public static final double MOTOR_TICKS_PER_REVOLUTION = 145.1;
    public static final double MAX_MOTOR_TICKS_PER_SECOND =
            MOTOR_FREE_SPEED_RPM * MOTOR_TICKS_PER_REVOLUTION / 60.0; // 2781.0833
    
    // ==================== DRIVETRAIN GEOMETRY ====================
    public static final double FIRST_STAGE_RATIO = 16.0 / 54.0;
    public static final double SECOND_STAGE_RATIO = 50.0 / 19.0;
    public static final double TOTAL_DRIVE_RATIO = FIRST_STAGE_RATIO * SECOND_STAGE_RATIO;
    public static final double WHEEL_DIAMETER_METERS = 0.06325; // 63.25 mm
    public static final double WHEEL_CIRCUMFERENCE_METERS = Math.PI * WHEEL_DIAMETER_METERS;
    public static final double TRACK_WIDTH_METERS = 0.3595;
    public static final double TRACK_WIDTH_INCHES = TRACK_WIDTH_METERS / 0.0254;
    public static final double POD_CENTER_OFFSET_INCHES = TRACK_WIDTH_INCHES / 2.0;
    public static final double MAX_WHEEL_SPEED_METERS_PER_SECOND =
            MOTOR_FREE_SPEED_RPM / 60.0 * TOTAL_DRIVE_RATIO * WHEEL_CIRCUMFERENCE_METERS;
    
    // ==================== DIAGNOSTIC LIMITS ====================
    // Safe testing speeds for commissioning
    public static final double MAX_TEST_POWER = 0.25; // For MotorEncoderDriveTest individual mode
    public static final double MAX_COMBINED_TEST_TICKS_PER_SECOND = 420.0; // For pod mode
}

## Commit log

2026-04-20 init motors and find steering diff angle
2026-04-20 Enhance README with project details and images
    Added project description and final assembly images for the differential swerve drivetrain.
2026-08-11 Change project name and modify assembly section
    Updated project name and added assembly details.
2026-08-11 Revise final assembly notes in README
    Updated the final assembly description to indicate issues with size and speed.
2026-08-11 Add BOM.csv with vendor and item details
    [BOM.csv]
2026-09-17 encoder push
2026-09-17 some changes
    [BOM.csv]
